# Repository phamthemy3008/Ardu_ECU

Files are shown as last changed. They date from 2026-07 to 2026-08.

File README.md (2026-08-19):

# Ardu_ECU — ECU Manual V1 (Version 7.9)

ECU (Engine Control Unit) cho động cơ phản lực mô hình mini (Enjet E86), chạy trên vi điều khiển ESP32.
Phiên bản **Manual V1** tập trung vào điều khiển thủ công và tự động qua **Web Serial API** & **Over-The-Air (OTA)**, đảm bảo độ tin cậy và chống nhiễu cao nhất trong môi trường công nghiệp/motor.

---

## Cấu Trúc Project

```
Ardu_ECU/
│
├── PROJECT_CURRENT/           ← Dự án đang phát triển (bắt đầu từ đây)
│   ├── Firmware/              
│   │   └── ECU_ManualV1/
│   │       └── ECU_ManualV1.ino   ← Code ESP32 (v7.9, mở bằng Arduino IDE / GitHub Actions)
│   ├── Tools/                 
│   │   └── index.html             ← Web Dashboard (v7.9, mở bằng Chrome/Edge)
│   ├── Hardware/                  ← Sơ đồ nguyên lý và Netlist PCB
│   └── Docs/                      ← Tài liệu kỹ thuật & Hướng dẫn triển khai
│
├── TEST/                      ← Firmware test riêng lẻ
├── REFERENCES/                ← Tài liệu và mã nguồn tham khảo
└── README.md
```

---

## Hướng Dẫn Chạy Web Dashboard Trên Windows 11 (Không Cần Cài Thêm Gì)

Web Dashboard được thiết kế theo chuẩn **Standalone Native HTML5 / JS Vanilla & Web Serial API**.

> [!IMPORTANT]
> **Yêu cầu**: Máy tính **Windows 11** + Trình duyệt **Google Chrome** hoặc **Microsoft Edge**.  
> **KHÔNG CẦN CÀI THÊM PHẦN MỀM GÌ**: Không cần cài Node.js, Python, hay web server. Chạy hoàn toàn offline (Zero Dependencies).

1. **Thao tác khởi chạy (Chế độ mặc định - Không cần cài Node.js)**:
   - Mở thư mục `PROJECT_CURRENT/Tools/` trong File Explorer.
   - Click đúp chuột vào file `index.html` (hoặc nhấp chuột phải chọn *Open with -> Google Chrome / Microsoft Edge*).
   - Trình duyệt sẽ mở trực tiếp file `file:///C:/.../index.html`.

2. **Kết nối Serial qua USB**:
   - Cắm cáp USB nối ESP32 với máy tính.
   - Bấm nút **"🔌 Kết Nối USB COM"** ở góc phải Web Dashboard.
   - Chọn đúng cổng COM của ESP32 (ví dụ: `COM3`, `COM4` - chip `CP210x` hoặc `CH340`) và bấm **Connect**.
   - Trạng thái sẽ báo `CỔNG COM ĐÃ MỞ (115200 baud, CRC-8)` và truyền/nhận dữ liệu lập tức.

3. **Khả năng sử dụng tính năng AI khi chạy Local**:
   - **Khi mở trực tiếp `index.html` (`file:///...`)**: Tất cả tính năng điều khiển Bơm/Đề/Van, Đồ thị Telemetry, Dừng khẩn cấp, Bảng Cài đặt Ngưỡng an toàn & Lưu `localStorage` đều **hoạt động 100% hoàn hảo không cần mạng**. Tuy nhiên, nút **"🧠 Phân Tích Dữ Liệu Log & Telemetry AI"** sẽ báo lỗi do không có server backend trung gian để gọi Gemini API.
   - **Để bật đầy đủ tính năng Chẩn Đoán AI khi chạy ở máy local**:
     1. Cài đặt **Node.js** (Lựa chọn thêm nếu muốn dùng AI).
     2. Tạo file `.env` tại thư mục gốc với nội dung `GEMINI_API_KEY=mã_api_key_của_bạn` (lấy miễn phí tại Google AI Studio).
     3. Mở Terminal / CMD tại thư mục dự án và chạy lệnh: `npm start` (hoặc `node server.js`).
     4. Mở trình duyệt truy cập `http://localhost:3000` -> Sử dụng đầy đủ tính năng phân tích & chẩn đoán sự cố tự động bằng Gemini AI!

---

## Bắt Đầu Với Firmware ESP32

1. **Upload Firmware**:
   - Mở file `PROJECT_CURRENT/Firmware/ECU_ManualV1/ECU_ManualV1.ino` bằng Arduino IDE.
   - Chọn Board **ESP32 Dev Module**, Baudrate 115200.
   - Thư viện cần: `Adafruit_MAX31855`, `SD` (xung PWM được điều khiển trực tiếp qua bộ tạo xung LEDC phần cứng của ESP32).

---

## Tính Năng Nổi Bật (Version 5.9)

- **Ghi Log Telemetry & Sự Kiện Lên Thẻ SD (`/ECUxxx.CSV`)**:
  - Tự động ghi nhật ký định kỳ 2Hz và hàng đợi sự kiện lỗi (`sdLogEvent`) ra file CSV trên thẻ MicroSD.
  - Các lệnh quản lý log qua Serial: `sdstatus`, `sdtest`, `set sdlog on|off`.

- **Tùy Chỉnh Ngưỡng An Toàn Trên Web UI (Safety Thresholds)**:
  - Cho phép thiết lập và lưu trên giao diện Web các ngưỡng: **PEGT 3s Max**, **EGT Max**, và **Max RPM**.
  - Dữ liệu được lưu vào **localStorage** của trình duyệt, tự động đồng bộ tới ECU khi kết nối và lưu vào `/ECUCFG.TXT` trên thẻ SD.

- **Cảnh Báo & Bảo Vệ An Toàn Tự Động**:
  - `ERR:E06` — Bảo vệ Quá Vòng Tua (Overrev) khi RPM vượt `Max RPM`.
  - `ERR:E02` — Bảo vệ Quá Nhiệt (Overheat) khi PEGT 3s hoặc EGT trực tiếp vượt ngưỡng cài đặt.
  - Khóa liên động 2 chiều Bơm - Van (`ERR:E01`, `EV:A01`, `EV:A02`).
  - Dừng khẩn cấp thổi khí làm mát buồng đốt (`estop` / `EV:A03`).
  - Nút cứng vật lý đa năng `BTN1` (IO22): Nhấp < 3s -> Dừng Khẩn Cấp làm mát; Giữ >= 3s -> Dừng Toàn Bộ (Full Shutdown).

- **Thuật Toán Gia Tốc Mượt Bơm & Đề (Smooth Ramps)**:
  - Pump Smoothstep S-Curve Ramp (1.5s): Đẩy ga nhiên liệu mượt chống dập lửa.
  - Starter Exponential Ramp (1.0s): Tăng ga đề theo đường cong mũ thắng ma sát nghỉ.
  - Công tắc Bật/Tắt ramp độc lập trên Web UI (`set pumpramp on|off`, `set starterramp on|off`).

- **Bộ Lọc RPM 7 Tầng Chuyên Sâu & Giao Thức Bảo Mật CRC-8**:
  - Loại bỏ hoàn toàn nhiễu cao tần từ ESC/Motor và đảm bảo tính toàn vẹn tín hiệu UART.

---

## Sơ Đồ Chân (Pinout) ESP32

| Thiết bị | Chân GPIO | Chú thích |
|---|---|---|
| **Cảm biến nhiệt (MAX31855)** | CLK=18, CS=5, DO=19 | Giao tiếp SPI (VSPI) |
| **Cảm biến vòng tua (RPM)** | 33 | Cảm biến từ/quang (KMZ10A / Hall) |
| **Bơm nhiên liệu (Pump)** | 26 | Tín hiệu PWM điều khiển ESC (LEDC CH0) |
| **Mô-tơ Đề (Starter)** | 25 | Tín hiệu PWM điều khiển ESC (LEDC CH1) |
| **Van nhiên liệu 1 (Valve 1)** | 17 | Tín hiệu Digital (Relay/Mosfet) |
| **Van khởi động 2 (Valve 2)** | 16 | Tín hiệu Digital (Relay/Mosfet) |
| **Đánh lửa (Igniter)** | 32 | Tín hiệu Digital (Relay/Mosfet) |
| **Thẻ nhớ MicroSD** | CS=13, SCK=14, MOSI=23, MISO=27 | Giao tiếp SPI (HSPI) |
| **Nút nhấn vật lý (BTN1)** | 22 | Nút đa năng Dừng Khẩn Cấp / Shutdown |
| **Đèn LED Trạng Thái** | 2 | Nháy Heartbeat 1Hz |

---

## Khắc Phục Sự Cố (Troubleshooting)

1. **Lỗi không kết nối được Web Serial:**
   - Trình duyệt báo `The port is already open`: Đảm bảo bạn đã đóng Serial Monitor trong Arduino IDE. Sử dụng nút "❌ Ngắt Kết Nối" trên Web để nhả cổng COM trước khi upload code.
   - Trình duyệt không có nút kết nối: Hãy dùng Chrome hoặc Edge bản mới nhất.

2. **Log báo `[RX NOISE DROPPED]` liên tục:**
   - Bình thường khi mạch chịu nhiễu điện từ nặng từ ESC/Motor. Firmware đã chặn các lệnh lỗi nhờ CRC-8.
   - Khắc phục phần cứng: Tiếp đất (GND) chung, xoắn cặp dây UART, sử dụng lõi Ferrite chống nhiễu.

3. **Thông báo lỗi EGT `ERR(SHORT_VCC)` hoặc `ERR(OPEN)`:**
   - Kiểm tra lại dây Thermocouple K (MAX31855). Dây bị đứt, lỏng, hoặc chạm vỏ máy.

4. **Lệnh debug RPM mới qua Serial:**
   - `rpmlearn`: Xem bảng 20 bin PWM ↔ RPM đã tự động học được.
   - `rpmlearn reset`: Xóa dữ liệu học và bắt đầu học lại.

---

## Liên Hệ & Đóng Góp

- Mọi đóng góp đều được chào đón. Xem thêm tại [GitHub Issues](https://github.com/phamthemy3089/Ardu_ECU/issues).

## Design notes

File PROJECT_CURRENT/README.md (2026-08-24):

# PROJECT_CURRENT — ECU Manual V1 (Version 8.0)

**Trạng thái**: Phiên bản v8.0 (Hoàn thiện & Ổn định)  
**Cập nhật**: 2026-08-24  

---

## Cấu Trúc Thư Mục

```
PROJECT_CURRENT/
│
├── Firmware/ECU_ManualV1/
│   └── ECU_ManualV1.ino           ← Firmware ESP32 (Arduino IDE / GitHub Actions, v8.0)
│
├── Tools/
│   └── index.html                 ← Web Dashboard & Web Serial ESP32 Flasher (Chrome/Edge, v8.0)
│
├── Hardware/
│   ├── 3D Printable Files/        ← File in 3D (Bendix Sleeve, Giá đỡ Motor Đề)
│   │   ├── Bendix Sleeve_10mm_NoSpring_Reinforced.stl   ← Ống áo Bendix cốt 10mm (Tự văng không lò xo)
│   │   ├── Bendix Sleeve_10.4mm_NoSpring_Reinforced.stl ← Ống áo Bendix cốt 10.4mm (Tự văng không lò xo)
│   │   ├── Bendix Sleeve_Reinforced.stl                ← Ống áo Bendix cốt 9mm (Bản gia cường)
│   │   ├── Bendix Sleeve.stl                           ← Ống áo Bendix cốt 9mm (Bản gốc)
│   │   ├── Brushless motor mount.stl                   ← Giá đỡ motor không chổi than
│   │   └── Brushed motor mount.stl                     ← Giá đỡ motor chổi than
│   ├── ECU_JET_20260723.net       ← Netlist PCB (PADS)
│   └── SCH_MinijetengineECU_20260723.json ← Sơ đồ mạch ECU (EasyEDA JSON)
│
├── Docs/
│   ├── JETENGINE_ECU_DESIGN_REFERENCE.md  ← Tài liệu thiết kế ECU
│   ├── STARTER_MOTOR_IMPLEMENTATION_GUIDE.md  ← Hướng dẫn triển khai Starter
│   ├── CHANGELOG.md               ← Nhãn lịch sử các phiên bản
│   └── BringUp_Logs/              ← Dữ liệu đo RPM thực tế (DSO152, Serial)
│
└── README.md                      ← File hướng dẫn này
```

---

## Hướng Dẫn Chạy Web Dashboard Trên Windows 11 (Không Cần Cài Thêm Gì)

Ứng dụng Web Dashboard được thiết kế theo tiêu chuẩn **Standalone Native HTML5 & Web Serial API**.

> [!IMPORTANT]
> **Yêu cầu hệ thống**: Máy tính chạy **Windows 11** + Trình duyệt **Google Chrome** hoặc **Microsoft Edge** (đã tích hợp sẵn Web Serial API từ phiên bản 89 trở lên).  
> **TUYỆT ĐỐI KHÔNG CẦN CÀI THÊM GÌ**: Không cần Node.js, không cần Python, không cần cài server web, không cần cài thêm thư viện phụ trợ (Zero Dependencies / Offline Ready).

### Các bước khởi chạy Web Dashboard:

1. **Khởi chạy giao diện (Chế độ mặc định - Offline 100% không cần Node.js)**:
   - Mở thư mục `PROJECT_CURRENT/Tools/` trên máy tính.
   - **Click đúp chuột** vào file `index.html` (hoặc chuột phải chọn *Open with -> Google Chrome / Microsoft Edge*).
   - Trình duyệt sẽ mở trực tiếp file dạng `file:///C:/.../PROJECT_CURRENT/Tools/index.html`.

2. **Kết nối USB COM với ESP32**:
   - Cắm cáp USB (MicroUSB / Type-C) nối board ESP32 vào máy tính Windows 11.
   - Trên giao diện Web Dashboard, bấm nút **"🔌 Kết Nối USB COM"** ở góc trên bên phải.
   - Trong cửa sổ popup của trình duyệt, chọn đúng cổng COM tương ứng của ESP32 (ví dụ: `COM3`, `COM4` - thường ghi tên chip USB `CP210x` hoặc `CH340`).
   - Bấm **Connect**. Màn hình console sẽ báo `CỔNG COM ĐÃ MỞ (115200 baud, CRC-8)` và toàn bộ dữ liệu telemetry sẽ cập nhật thời gian thực.

3. **Tính Năng Nạp Firmware Trực Tiếp Trên Browser (Web Serial ESP32 Flasher)**:
   - Web Dashboard tích hợp thư viện `esptool-js` giúp người dùng nạp file `firmware.bin` trực tiếp vào ESP32 thông qua trình duyệt mà không cần cài đặt Python hay Arduino IDE.
   - Bấm nút **"🔥 Nạp Firmware USB"**, chọn file `firmware.bin`, đưa ESP32 về chế độ Flash (nếu cần) và bấm **Program Firmware**.

4. **Khả năng sử dụng tính năng Chẩn Đoán AI khi chạy ở máy Local**:
   - **Chạy trực tiếp HTML (`file:///...`)**: Tất cả các tính năng cốt lõi (điều khiển Bơm/Đề/Van, Đồ thị Telemetry, Dừng khẩn cấp, Bảng Cài đặt Ngưỡng an toàn & Lưu `localStorage`, Cấu hình Wi-Fi/OTA) **hoạt động 100% mượt mà không cần mạng**. Riêng nút **"🧠 Phân Tích Dữ Liệu Log & Telemetry AI"** cần backend server để gọi API Gemini.
   - **Để bật tính năng Chẩn Đoán AI Gemini trên máy Local**:
     1. Cài đặt **Node.js** trên Windows 11 (nếu chưa có).
     2. Tạo file `.env` tại thư mục gốc project với nội dung: `GEMINI_API_KEY=mã_key_của_bạn` (lấy tại Google AI Studio).
     3. Chạy lệnh `npm start` (hoặc `node server.js`) trong Terminal.
     4. Mở trình duyệt tại địa chỉ `http://localhost:3000` -> Sử dụng đầy đủ tính năng phân tích & chẩn đoán lỗi chuyên sâu bằng Gemini AI!

5. **Lưu ý trên Windows 11 & Khắc phục sự cố**:
   - **Driver USB**: Windows 11 đa số tự động nhận diện chip CH340 / CP2102. Nếu không thấy xuất hiện cổng COM trong danh sách, hãy cài driver `CP210x Universal Windows Driver` hoặc `CH340 Windows Driver`.
   - **Lỗi Cổng COM bị chiếm dụng (`The port is already open`)**: Hãy chắc chắn rằng bạn đã tắt **Serial Monitor** hoặc **Serial Plotter** trong phần mềm Arduino IDE (hoặc các phần mềm terminal như PuTTY) trước khi bấm kết nối trên Web.

---

## Hướng Dẫn Upload Firmware ESP32

### Cách 1: Tự động Biên Dịch & Nạp Qua CI/CD GitHub Actions (Khuyên dùng)
- Mỗi khi push code lên nhánh `main`, GitHub Actions (`.github/workflows/compile-firmware.yml`) sẽ tự động cài đặt `arduino-cli`, biên dịch mã nguồn `ECU_ManualV1.ino` và tạo sẵn file `firmware.bin` tại thư mục `PROJECT_CURRENT/Firmware/ECU_ManualV1/firmware.bin`.
- Bạn chỉ cần tải file `firmware.bin` về và dùng nút **"🔥 Nạp Firmware USB"** trên Web Dashboard để nạp.

### Cách 2: Upload Bằng Arduino IDE Thủ Công
1. Mở file `Firmware/ECU_ManualV1/ECU_ManualV1.ino` bằng **Arduino IDE**.
2. Chọn Board: **ESP32 Dev Module** (hoặc NodeMCU-32S).
3. Thư viện phần cứng cần có trong Arduino IDE:
   - `Adafruit_MAX31855` (đọc cảm biến nhiệt độ EGT qua SPI).
   - `SD` (đọc/ghi cấu hình & log dữ liệu ra thẻ MicroSD).
   - *Lưu ý*: Tín hiệu ESC PWM cho Bơm & Đề được điều khiển bằng bộ tạo xung LEDC phần cứng có sẵn của ESP32 — **không** cần thư viện `ESP32Servo`.
4. Upload Firmware → Baudrate Serial mặc định **115200 baud**.

---

## Tính Năng Chính & Cải Tiến (v8.0)

- **Kiến Trúc Đa Nhân FreeRTOS Cô Lập Tuyệt Đối (Multi-Core Isolation)**:
  - **Core 1 (Engine Control Core)**: Xử lý độc quyền các tác vụ thời gian thực mức phần cứng (RPM ISR, cảm biến EGT SPI, điều xung ESC PWM, bộ lọc RPM 7 tầng, logic ngắt khẩn cấp). Đảm bảo tính thời gian thực 100% không bị trễ do mạng hay thẻ SD.
  - **Core 0 (System & Network Core)**: Đảm nhận việc ghi thẻ SD bất đồng bộ (`sdQueue`), kết nối Wi-Fi, xử lý giao thức Web Serial, quét mạng Wi-Fi không chặn (`WiFi.scanNetworks(true)`) và cập nhật firmware qua mạng Async OTA (`ArduinoOTA`).

- **Cập Nhật Firmware Qua Mạng OTA Bất Đồng Bộ (`ArduinoOTA`)**:
  - Hỗ trợ nạp firmware không dây qua mạng Wi-Fi local mà không cần cắm cáp USB.
  - Tự động ngắt toàn bộ động cơ (`allOff()`) khi bắt đầu nhận bản nạp OTA để đảm bảo an toàn tuyệt đối.

- **Trình Quét Mạng Wi-Fi Không Chặn & Modal Chọn Mạng**:
  - Lệnh `wifi scan` hoạt động ở chế độ Async không gây đơ lag thuật toán tính toán RPM/EGT.
  - Web Dashboard hiển thị danh sách các mạng Wi-Fi quét được, nhấp chuột để chọn SSID tự động và điền mật khẩu.

- **Ghi Log Telemetry & Sự Kiện Lên Thẻ SD (`/ECUxxx.CSV`) Kháng Lỗi C++**:
  - Tự động tạo file nhật ký xoay vòng (`ECU000.CSV` .. `ECU999.CSV`) khi khởi động.
  - Hàng đợi log sự kiện phi đối xứng `sdLogEvent` hỗ trợ hai kiểu tham số `sdLogEvent(const char*)` và `sdLogEvent(const String&)` có bảo vệ null-pointer, đẩy vào queue FreeRTOS truyền dữ liệu thread-safe.

- **Tùy Chỉnh Ngưỡng An Toàn Linh Hoạt (Safety Thresholds Configuration)**:
  - Cho phép người dùng trực tiếp thay đổi và lưu các ngưỡng an toàn trên giao diện Web Dashboard:
    - **PEGT 3s Max (°C)**: Giới hạn dự báo nhiệt độ 3s (mặc định 740°C, tùy chỉnh 300 - 1200°C).
    - **EGT Max (°C)**: Giới hạn nhiệt độ EGT đo trực tiếp (mặc định 800°C, tùy chỉnh 300 - 1200°C).
    - **Max RPM**: Giới hạn vòng tua tối đa chống overrev (mặc định 160.000 RPM, tùy chỉnh 5.000 - 250.000 RPM).
  - Tự động lưu vào **localStorage** của trình duyệt và truyền ngay các lệnh thiết lập (`set pegtmax`, `set egtmax`, `set maxrpm`) tới ECU khi kết nối thành công. Đồng thời được lưu lâu dài vào file cấu hình `/ECUCFG.TXT` trên thẻ SD.

- **Bảo Vệ Chống Overrev & Bùng Nhiệt Toàn Diện**:
  - `ERR:E06`: Tự động ngắt Bơm nhiên liệu và kích hoạt Dừng Khẩn Cấp khi vòng tua lọc `fRpm` vượt ngưỡng `maxRpmLimit`.
  - `ERR:E02`: Tự động ngắt Bơm nhiên liệu và kích hoạt làm mát khi `PEGT 3s > pegtLimit` hoặc `EGT > egtMaxLimit`.

- **Thuật Toán Gia Tốc Mượt Bơm (Pump S-Curve Smoothstep Ramp 1.5s)**: Gia tốc ga nhiên liệu mượt mà theo đa thức bậc 3 ($3x^2 - 2x^3$), giúp động cơ rú ga mượt hệt như máy bay thật, chống sặc dầu & dập lửa.

- **Thuật Toán Gia Tốc Đề (Starter Exponential Ramp Up 1.0s)**: Gia tốc lực kéo mô-tơ Đề theo đường cong mũ lũy thừa, thắng lực ma sát nghỉ ban đầu mà không làm xóc nhông Bendix hay kẹt motor.

- **Bộ Lọc RPM 7 Tầng Chuyên Sâu**: Min Pulse → Dynamic Mask 75% → Median-5 → Dynamic Outlier Guard → Rate Limiter → Adaptive PWM-Aware Learning (Monotonicity Floor + Hysteresis) → Cascaded Dual-EMA Bậc 2.

- **Dừng Khẩn Cấp Thổi Khí Nóng (`estop`)**: Ngắt Bơm/Lửa/Van nhưng tự động bật/giữ Mô-tơ Đề 1300 µs để làm mát buồng đốt khi EGT > 80°C.

- **Nút Cứng Vật Lý Đa Năng (`BTN1` / IO22)**:
  - Nhấp 1 lần (< 3s): Kích hoạt Dừng Khẩn Cấp làm mát.
  - Nhấn giữ 3s (>= 3s): Dừng Toàn Bộ (Full Shutdown, ngắt cả Đề).

- **Khóa An Toàn 2 Chiều (Pump-Valve Interlock)**:
  - Không cho bật Bơm khi cả 2 van nhiên liệu đang ĐÓNG (`ERR:E01`).
  - Tự động ngắt Bơm khi cả 2 van bị đóng (`EV:A02`).
  - Tự động đóng cả 2 van khi tắt Bơm (`EV:A01`).

- **Giao Thức Bảo Mật CRC-8 & Web Serial API**: Loại bỏ 100% lệnh rác do nhiễu cao tần từ ESC/Motor.

---

## Bảng Mã Sự Kiện & Mã Lỗi (Event & Error Code Dictionary)

| Mã Serial | Loại | Ý Nghĩa | Thông Báo Tiếng Việt Hiển Thị Trên Web Dashboard |
|---|---|---|---|
| `ERR:E01` | Cảnh báo | Bật Bơm khi cả 2 van đóng | `⚠️ CẢNH BÁO AN TOÀN: Cả 2 van nhiên liệu đều đang ĐÓNG! Vui lòng mở ít nhất 1 van trước.` |
| `ERR:E02` | Khẩn cấp | Quá nhiệt PEGT / EGT vượt ngưỡng | `🛑 CẢNH BẢO QUÁ NHIỆT: Nhiệt độ EGT/PEGT vượt ngưỡng an toàn! Đã tự động NGẮT BƠM & THỔI LÀM MÁT.` |
| `ERR:E06` | Khẩn cấp | Quá vòng tua RPM > Max RPM | `🛑 CẢNH BẢO QUÁ VÒNG TUA: Vòng tua (RPM) vượt ngưỡng tối đa! Đã tự động NGẮT BƠM NHIÊN LIỆU.` |
| `EV:A01`  | Thông tin | Tắt Bơm -> Tự đóng 2 van | `ℹ️ TỰ ĐỘNG KHÓA: Đã Tắt Bơm -> Tự động đóng cả 2 Van nhiên liệu (V1 & V2).` |
| `EV:A02`  | Thông tin | Đóng 2 van -> Tự ngắt Bơm | `ℹ️ TỰ ĐỘNG KHÓA: Đã đóng cả 2 Van -> Tự động ngắt Bơm nhiên liệu.` |
| `EV:A03`  | Khẩn cấp | Dừng Khẩn Cấp -> Thổi khí 1300µs | `🛑 DỪNG KHẨN CẤP: Ngắt Bơm & Lửa/Van -> Tự động bật Đề 1300µs thổi khí làm mát.` |
| `EV:A04`  | Thông tin | Dừng Khẩn Cấp -> Máy nguội <= 80°C | `ℹ️ DỪNG KHẨN CẤP: Đã ngắt Bơm & Lửa/Van (Máy đã nguội <= 80°C).` |
| `EV:A05`  | Khẩn cấp | Nút 3s / Dừng Toàn Bộ | `⚡ DỪNG TOÀN BỘ: Đã ngắt 100% tất cả thiết bị (Bơm, Đề, Lửa, Van).` |

---

## Pinout ESP32

| Chức năng | GPIO | Ghép nối / Chú thích |
|---|---|---|
| MAX31855 CLK/CS/DO | 18 / 5 / 19 | SPI (VSPI) |
| RPM Sensor | **33** | Cảm biến từ/quang (KMZ10A / Hall) |
| Pump ESC | 26 (LEDC CH0) | Tín hiệu PWM ESC Bơm nhiên liệu |
| Starter ESC | 25 (LEDC CH1) | Tín hiệu PWM ESC Mô-tơ Đề |
| Valve 1 / Valve 2 | 17 / 16 | Tín hiệu Digital điều khiển van |
| Ignition/Glow | 32 | Tín hiệu Digital điều khiển đánh lửa |
| SD CS/SCK/MOSI/MISO | 13 / 14 / 23 / 27 | Thẻ nhớ MicroSD (HSPI) |
| User Button (BTN1) | 22 | Nút nhấn cứng đa năng (Active LOW) |
| Status LED | 2 | Nháy Heartbeat 1Hz |

---

## Cảnh Báo An Toàn

- ESP32 chỉ chịu **3.3V** — dùng level converter cho tín hiệu 5V
- Chỉ dùng **thermocouple loại K**
- Cảm biến RPM KMZ10A cần hiệu chỉnh trimpot **RP1/RP2/RP3** trước khi dùng
- ESP32 cần nguồn điện riêng (không cấp qua USB khi motor chạy)

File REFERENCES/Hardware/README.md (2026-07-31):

# Hardware Directory

Thư mục chứa tất cả các tệp liên quan đến phần cứng của dự án Ardu_ECU.

## 📂 Sub-directories

### **Schematics/** - Sơ đồ mạch điện
Chứa tất cả các tệp sơ đồ và thiết kế mạch điện.

**Files**:
- `ECU Rev9-10 Schematic.pdf` - Schema cho Rev 9 và 10
- `Schematic_Ardu ECU_Rev 11.pdf` - Schema cho Rev 11 (ổn định hiện tại)
*(Lưu ý: Các file schema mới nhất nằm trong thư mục `../../PROJECT_CURRENT/Hardware/`)*

### **Components/** - Linh kiện và tài liệu
Chứa hình ảnh và thông số kỹ thuật của các linh kiện được sử dụng.

**Components**:
- `5v-to-3-3v-logic-level-converter-500x500.jpg` - Logic level converter
- `CK1602 Power Supply.jpg` - Power supply unit
- `ESP32 Dev Kit.jpeg` - Main microcontroller (NodeMCU 32S)
- `LR-7843.jpg` - Additional component

### **3D Printable Files/** - Các file in 3D
Chứa các file STL cho các bộ phận cơ học có thể in 3D.

**Files**:
- `Bendix Sleeve.stl` - Sleeves for starter motor
- `Brushed motor mount.stl` - Mount cho động cơ brushed
- `Brushless motor mount.stl` - Mount cho động cơ brushless

## 🔧 Hardware Overview

### **Core Components**:
1. **Microcontroller**: ESP32 DevKit V1 (NodeMCU-32S)
2. **Thermocouple Reader**: MAX31855 (for EGT measurement)
3. **SD Card Module**: For data logging
4. **Power Supply**: CK1602 unit
5. **Logic Level Converter**: 5V to 3.3V conversion
6. **Control Outputs**:
   - Starter motor controller (brushed or brushless)
   - Fuel pump controller (ESC or similar)
   - Ignition control (glow plug driver)
   - Gas valve solenoid control (MOSFET module)

### **Sensors**:
- **EGT Sensor**: K-type Thermocouple with MAX31855
- **RPM Sensor**: Magnetic (Hall effect) or Optical sensor
- **Optional**: Pressure sensors, Load cells

## 📐 Design Files

### **Latest Reference Files** (2026-07-23):
- `../../PROJECT_CURRENT/Hardware/ECU_JET_20260723.net` - Netlist mạch ECU mới nhất (gồm cả RPM sensor)
- `../../PROJECT_CURRENT/Hardware/SCH_MinijetengineECU_20260723.json` - Current ECU design schema

These are reference files from the current system implementation (ManualV1 v5.3) and can be used as guidelines for future designs.

## 🚀 Assembly Notes

1. **PCB Layout**: Refer to schematics for component placement
2. **3D Printed Parts**: Use `.stl` files for 3D printing
3. **Component Mounting**: Follow schematic for orientation and pin connections
4. **Wiring**: Carefully follow schematic connections to avoid damage

## ⚠️ Important Warnings

- **Voltage**: ESP32 operates at 3.3V - use logic level converter for 5V devices
- **Power**: Use proper power supply rated for your application
- **Thermocouple**: K-type only - do not use other types
- **High Temperature**: Mount components away from engine exhaust

## 📊 Revision History

| Revision | Date | Key Features |
|---|---|---|
| Rev 9 | Early | Initial design |
| Rev 10 | - | WiFi control, OLED display |
| Rev 11 | - | SD Card, dual-core processing, major redesign |
| Rev 12 TC10 | Legacy | Multi-sensor support, Kero start |
| TestV1_EGT_DRY_START | Legacy | Firmware cũ, có Auto-start, WiFi |
| ManualV1 (v5.3) | Current | Bản hiện tại, Manual Serial Control, Compact Event Codes, Interlock & Toast Banners |

---

For detailed firmware information, see [Firmware/README.md](../Firmware/README.md)

For project overview, see [README.md](../README.md)

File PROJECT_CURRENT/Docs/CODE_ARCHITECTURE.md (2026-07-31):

# ECU Manual V1 Firmware — Code Architecture & Understanding Guide

**Firmware**: `ECU_ManualV1.ino` (Version 4.2)
**Tools**: `index.html` (Web Serial Dashboard)
**Platform**: ESP32 (NodeMCU-32S), Arduino core 2.x **or** 3.x
**Language**: Arduino C++

> **Note on line numbers**: this guide navigates by **function / symbol name**, not
> line numbers — the firmware evolves and hard line references drift. Use your
> editor's symbol search. A companion changelog of behaviour changes lives in
> `CODE_REVIEW_FINDINGS.md`.

---

## 🏗️ Overall Architecture

State-machine firmware. One non-blocking `loop()` drives everything:

```
loop():
  1. server.handleClient()          (Web UI, if started)
  2. drain Serial -> handleCommand()
  3. handleUserButton()
  4. manual auto-off timers          (ign / starter / pump / valve1 / valve2)
  5. updateActiveTest()              (Test Wizard countdowns)
  6. isStage2Armed()                 (auto-disarm after 10s)
  7. updateRpm(); updateEgt()        (sensors)
  8. mode switch:  updateStarting / updateIdling / updateOperating / updateCooldown
  9. checkFailures()                 (all aborts evaluated here)
  10. applyOutputs()                 (write ESC PWM + digital outputs)
  11. updateStatusLed()
  12. updateSdTelemetry(); flushSdEventQueue()   (deferred SD writes)
  13. printStatus(false)             (throttled serial status)
```

Fuel/RPM/EGT control is re-evaluated every loop; safety checks (`checkFailures`)
run **after** the mode update and **before** `applyOutputs()`.

---

## ⚙️ PWM Driver — raw LEDC (not ESP32Servo)

ESC outputs (pump + starter) are driven by the ESP32 **LEDC** peripheral directly,
**not** the `ESP32Servo` library (which produced an unstable pulse on some core
versions and stuttered the ESC — see `CLAUDE.md`).

```cpp
escAttach(pin, legacyChannel)   // ledcAttach() on core >=3, ledcSetup+ledcAttachPin on core <3
escWriteUs(pin, legacyChannel, us)  // duty = us * 65535 / 20000  (50 Hz, 16-bit)
```
- 50 Hz frame, 16-bit resolution → 1000 µs = duty 3276, 2000 µs = duty 6553.
- Core version detected via `ESP_ARDUINO_VERSION_MAJOR`.

> **Arduino gotcha**: because `escAttach`/`escWriteUs` are the first functions in the
> sketch, the IDE injects auto-generated prototypes ahead of the enum definitions.
> The state enums (`EcuMode`, `StartStage`, `RpmNoiseLevel`, `TestId`, `TestResult`)
> are therefore **forward-declared** near the top so those prototypes compile.

---

## 🎯 Core State Machine

### ECU Modes
```cpp
enum EcuMode : uint8_t {
  MODE_WAITING, MODE_STARTING, MODE_IDLING,
  MODE_OPERATING, MODE_COOLDOWN, MODE_ABORTED
};
```

### Start Stages
```cpp
enum StartStage : uint8_t {
  ST_NONE, ST_PURGE, ST_SPINUP_PREHEAT,
  ST_INTRO_FUEL, ST_POST_IGNITION_HEAT, ST_ACCEL_TO_IDLE
};
```

### Mode transitions
```
WAITING
  │ arm (button hold 2s / arm2) then start (button hold 3s / startidle)
  ▼
STARTING  (ST_PURGE → ST_SPINUP_PREHEAT → ST_INTRO_FUEL → ST_POST_IGNITION_HEAT → ST_ACCEL_TO_IDLE)
  │ idle RPM reached  (enterMode records runningSinceMs here)
  ▼
IDLING ⇄ OPERATING   (throttle >0 / =0 toggles; does NOT reset runningSinceMs)
  │ soft stop / any abort
  ▼
COOLDOWN (starter airflow, fuel/ign/valves OFF)
  │ min time + (EGT cool OR timeout)
  ▼
WAITING            (after soft stop)   or   ABORTED (after an abort)
```

`ABORTED` is left only by `clearabort` (sets `abortAcknowledged`) or the physical
button hold. `stop`/`off` do **not** clear ABORTED (interlock).

---

## 📊 Key Data Structures

### Config (`struct Config cfg`)
Runtime configuration; the struct values are **power-on defaults**, most are
overridable at runtime via `set ...` (Serial/Web). Notable fields:

| Field | Default | Meaning |
|---|---|---|
| `autoStartEnabled` | false | Auto-idle at boot (off) |
| `requireEgtForStart` / `allowDryStartWhenEgtFault` | true | EGT gating / dry-start fallback |
| `requireRpmForStart`, `abortOnEgtFault`, `abortOnRpmFault` | true | Abort enables |
| `ignitionThresholdC` | 100 | "combusting" / ignition threshold |
| `maxEgtC` | 680 | OVER_TEMP abort limit |
| `maxTempGradientCps` | 200 | EGT rise-rate limit (steady state only) — `set maxgrad` |
| `idleRpm` / `maxRpm` / `rpmTolerance` | 42000 / 110000 / 5000 | RPM targets & deadband |
| `flameoutRpm` / `starterReleaseRpm` | 15000 / 24000 | flame-out / starter release |
| `starterPurgeUs` / `starterSpinUs` / `starterAssistUs` | 1100 / 1200 / 1200 | crank PWM — `set purgeus/spinus/assistus` |
| `introFuelUs` | 1160 (~50 ml/min) | light-off fuel dose (kept **< idle**) — `set intro` |
| `idleFuelUs` / `maxFuelUs` | 1175 / 1260 | idle / max fuel — `set idleus/maxus` |
| `pumpTestUs` | 1210 | bench pump-prime PWM, **separate** from introFuelUs — `set pumptestus` |
| `commWatchdogEnabled` / `commTimeoutMs` | true / 8000 | operator-link watchdog |
| cooldown / accel-to-idle / ramp timings | — | various `set ...` |

> All PWM/limit tuning setters are **rejected unless WAITING/ABORTED** so a stray
> command can't move a live setpoint or the protection envelope mid-run.

### EgtState `egt`
`ok, c, prevC, gradientCps, fault, lastReadMs, lastGoodMs`.

### RpmData `rpmData`
`rpm` (chosen source), `rpmPeriod` (instantaneous), `rpmWindow` (100 ms average),
`avgIntervalUs`, `jitterPct` (CV = stddev/mean), `rejectPct`, `rpmDiffPct`,
`rawEdges/acceptedWindow/rejectedEdges`, `noise` (RpmNoiseLevel), `signalRecent`,
`restPulseNoise`.

---

## 🔌 Pin Configuration

| Pin | Function | Dir | Type |
|-----|---|-----|---|
| 18 / 5 / 19 | EGT CLK / CS / DO | — | SPI (MAX31855) |
| 33 | RPM sensor | IN | Digital (ISR) |
| 26 | Pump ESC | OUT | LEDC PWM 50 Hz |
| 25 | Starter ESC | OUT | LEDC PWM 50 Hz |
| 17 | Valve 1 (Start solenoid) | OUT | Digital |
| 16 | Valve 2 (Main oil) | OUT | Digital |
| 32 | Ignition / glow | OUT | Digital |
| 22 | User button | IN | Digital (active-low) |
| 2 | Status LED | OUT | Digital (active-low) |
| 13 / 14 / 23 / 27 | SD CS / SCK / MOSI / MISO | — | SPI |

Valve roles (per EnJet E86/G3 manual): **Valve1** = start solenoid, open only
during `MODE_STARTING`; **Valve2** = main oil valve, open whenever fuel is commanded.

---

## 🔋 Subsystems

### 1. EGT (MAX31855)
- `updateEgt()` polls every `EGT_READ_PERIOD_MS` (120 ms); `readError()` then
  `readCelsius()`; `isnan`/fault → `egt.ok=false`, gradient zeroed.
- `gradientCps` = ΔT/Δt.
- **Two look-aheads with different jobs**:
  - Fuel control: 3 s projected temp (`egt.c + 3·gradient ≥ maxEgtC`) — steady state.
  - OVER_TEMP abort: short `EGT_ABORT_LOOKAHEAD_S = 0.2 s` — compensates ~1 sample of
    read staleness so a fast rise can't overshoot `maxEgtC` by a sample.
- **Stuck-sensor hint** (log only, never aborts): if `egt.c` is byte-for-byte
  unchanged for `EGT_STUCK_WARN_MS` (6 s) while combusting, logs a warning — a
  frozen-but-valid thermocouple isn't caught by open/short fault detection.
- **Dry-start**: if EGT is OPEN, `startidle` becomes a starter/RPM-only test
  (pump/valves/ign forced OFF every loop); real fuel start still needs valid EGT.

### 2. RPM sensing (ISR on GPIO 33)
- `rpmISR()` timestamps each edge with `micros()` (coerced to non-zero to avoid the
  "no edge yet" sentinel colliding at the ~71 min wrap).
- **Two-stage de-glitch**: (a) fixed min quiet-period `rpmMinPulseUs` (120 µs default,
  `set rpmfilter`); (b) adaptive half-period mask — reject an edge closer than half
  the last accepted period (an isolated EMI spike after a quiet gap).
- `updateRpm()` snapshots ISR counters inside `noInterrupts()` (the only `uint64_t`
  accumulators are read atomically there), computes:
  - `rpmWindow = accepted · 60e6 / (windowUs · ppr)`  (100 ms average)
  - `rpmPeriod = 60e6 / (lastPeriod · ppr)`  (instantaneous, preferred when recent)
  - `jitterPct` = **coefficient of variation** (stddev/mean), so one stray interval
    doesn't swamp an otherwise-clean signal.
- **REST guard**: while WAITING with all outputs safe, isolated edges are treated as
  noise (`RPM_REST_NOISE`, control RPM forced 0) to stop 1–3 false pulses reading as RPM.

Noise classes (`classifyRpmNoise`):
```
NO_SIGNAL : no recent signal and raw==0
NOISY     : raw>1 & accepted==0 (a lone post-reset priming edge is NOT noise), OR rejected>=3/rejectPct>20, OR jitter>30% (>=5 intervals), OR rpmDiff>30%
WARN      : rejected>0/rejectPct>5,  OR jitter>15% (>=3 intervals),           OR rpmDiff>15%
CLEAN     : otherwise
REST_NOISE: rest-guard active
```

### 3. Fuel control (hybrid, closed-loop to RPM)
```
target RPM ──► fuelTargetUs (nudged ±fuelStepUs vs RPM error, gated by EGT)
                    │
             pumpUs ── ramps toward target 1 µs / step (accel/decel delays)
```
- Pump map (`kPumpMap`, µs → ml/min), interpolated by `flowFromUs`/`usFromFlow`:
  `1000→0, 1160→50, 1175→80, 1250→265, 1260→280, 1265→360, 1270→560, 1300→600`.
- **Over-temp emergency cut**: when `egtRequestsFuelCut()` fires, `pumpUs` steps down
  by `fuelCutStepUs` at the fast decel rate (~40 µs/s), not the old ~2 µs/s ramp that
  could never keep up before the hard abort.
- **Governed ceiling**: `updateOperating()` targets `maxRpm − rpmTolerance` at 100%
  throttle, so full throttle doesn't drive the engine into its own OVERSPEED abort.
- During `MODE_STARTING` the gradient / 3 s look-ahead fuel limiting is **skipped**
  (a fast EGT rise at light-off is expected); only absolute `maxEgtC` + the abort
  look-ahead protect there, so the start can actually reach idle.

### 4. User button (GPIO 22, active-low, 35 ms debounce)
```
WAITING : short=status · hold 2s=ARM
ARMED   : hold 3s=START IDLE           (button runs set runStartedByButton)
STARTING/IDLING/OPERATING : any press=SOFT STOP
ABORTED : hold 2s=clear (if EGT safe/deliberate)
```

### 5. Output control
`applyOutputs()` constrains ESC values to 1000–2000 µs and writes PWM + digital
outputs. `forceSafeOutputs()` slams everything safe (ESC 1000 µs, ign/valves OFF,
clears the valve auto-off timers; the ign/starter/pump timers are cleared in
`stage2Off()`/`beginAutoIdle()`). Manual bench outputs (ignpulse/starttest/
pumptest/valve-on) all have loop auto-off timers.

---

## 🚀 Start Sequence

```
ST_PURGE (purgeTimeMs 3s)         starter=starterPurgeUs(1100), no fuel/ign
ST_SPINUP_PREHEAT (preheatMs)     starter=starterSpinUs(1200), igniter ON (preheat); needs cranking RPM (starterProveMinRpm)
ST_INTRO_FUEL                     igniter still ON, valves open, fuel=introFuelUs(1160); wait ignition/fuel-confirm
ST_POST_IGNITION_HEAT             hold fuel, watch RPM rise; starter -> starterAssistUs(1200)
ST_ACCEL_TO_IDLE                  closed-loop fuel to idleRpm; starter releases; timeout=accelToIdleTimeoutMs(20s)
  └─ idle stable ► MODE_IDLING
```
Every stage is time-bounded (no infinite hang). Dry-start runs the same stages with
fuel/valves/ign forced OFF and its own RPM-test timeouts.

---

## 🔒 Safety — `checkFailures()` (runs every loop, not in WAITING/COOLDOWN/ABORTED)

Order and conditions:
1. **COMM_TIMEOUT** — only while RUNNING (IDLING/OPERATING) with no operator link
   within `commTimeoutMs`. **Exempt** for button-started runs (`runStartedByButton`);
   re-engages on any remote command. MODE_STARTING is deliberately NOT covered (the
   automated start outlasts `commTimeoutMs` with nothing to refresh the link, so
   covering it would false-abort a Serial-only start); the start is bounded instead
   by the per-stage timeouts.
2. **EGT_FAULT** — sensor invalid (unless dry-start).
3. **OVER_TEMP** — `egt.c ≥ maxEgtC` OR the 0.2 s look-ahead projects past it.
4. **OVERSPEED** — usable RPM `≥ maxRpm`.
5. **RPM_SIGNAL_LOST** — while fueled: in STARTING, pulse-recency only (so ignition
   EMI classifying NOISY doesn't false-abort a light-off); in IDLING/OPERATING, no
   pulse within `FUELED_RPM_LOSS_TIMEOUT_MS` (400 ms → fast flameout cut), OR a
   NOISY-but-present signal sustained ≥ `RPM_NOISY_ABORT_MS` (300 ms debounce, so a
   one-window EMI blip can't shut down a healthy engine). Suppressed for one
   loss-timeout after any `resetRpmStats()` so a stats reset can't read as loss.
   The same recency-not-NOISY logic is used by the SPINUP starter-prove checks.
6. **FLAMEOUT** — RPM `< flameoutRpm` after a 1.5 s grace **anchored to
   `runningSinceMs`** (first stable idle), so throttle toggles can't re-arm/mask it.

Other interlocks:
- `requestStop()` acts only in STARTING/IDLING/OPERATING (no ABORTED backdoor).
- `stage2Off()`/`off` in ABORTED, **and** in COOLDOWN while `cooldownAfterAbort` is
  true, only re-asserts safe outputs and does not transition to WAITING — it lets
  a post-abort cooldown finish into ABORTED instead of shortcutting past it;
  requires `clearabort` either way.
- `ignpulse` and `valve1/valve2 on` are blocked while EGT is hot
  (`fuelCommandBlockedByHotEgt`); `starttest` (starter only) stays allowed. The
  Test Wizard's `test ign`/`test starter_ign`/`test valve1`/`test valve2` apply the
  same hot-EGT guard (`test starter` is exempt, same reasoning).
- All outputs OFF on boot; ESC held at 1000 µs during arm.

---

## 🌐 Web UI (SoftAP)

- SSID `ECU_TestV1`, password `admin1234` (**weak default — change `WEB_PASS`
  before live use**; anyone on the AP can arm/start via `/cmd`), IP `192.168.4.1`.
- Routes: `/` (dashboard), `/api` (JSON status, `?act=0` when tab hidden so a
  walked-away session times out instead of keeping the watchdog alive), `/cmd?c=...`
  (runs `handleCommand`, same interlocks as Serial).
- Dashboard: status cards, controls, **Test Wizard**, **Tune quick set** and
  **Starter & Fuel PWM** panels whose inputs **auto-populate from live config**
  (so clicking Set can't silently change a limit), **Starter Manual Test**, event log.
- `webStatusJson()` builds the payload by hand (no ArduinoJson); `jsonEscape()`
  escapes `"` `\` and all control chars.

---

## 💾 SD Card Logging

- `sdLogEvent()` snapshots a CSV line and queues it (ring buffer, drop-oldest); the
  **blocking** `SD.open/println/close` happens in `flushSdEventQueue()` and
  `updateSdTelemetry()` late in the loop, after safety checks.
- **Backoff**: after 5 consecutive write failures `sdOk` is cleared so a pulled card
  stops blocking the control loop every cycle (re-enable requires reboot).
- Telemetry ~2 lines/s while active; CSV columns include time, mode, stage, EGT,
  gradient, RPM, fuel target, pump/start µs, ign, valves, throttle, abort reason.

---

## ✅ Test Wizard / Checklist

Nine tests (`test egt|rpm_noise|ign|starter|starter_ign|valve1|valve2|pump|kill`),
results `TEST_NOT_RUN/RUNNING/PASS/FAIL`. Optionally required before `startidle`
(`set checklist on/off`). Timed tests auto-off; `beginAutoIdle()` cancels any active
test so a countdown can't fire mid-start.

---

## 🎮 Serial / Web Commands (selected)

```
help | status | showcfg | rpmreset | stop | off
arm2 | autostart on/off | startidle | clearabort [force]
rpmdetail [on|off]
ignpulse <ms> | starttest <us> <ms> | pumptest <us> [ms]      (arm2, WAITING/ABORTED; EGT-hot blocked where fuel/ign)
valve1 on/off | valve2 on/off                                 (auto-off 10s; EGT-hot blocked)
test <name> | checklist | resetcheck | confirmkill | set checklist on/off
set intro/idleus/maxus/pumptestus <us>                        (WAITING/ABORTED only)
set purgeus/spinus/assistus <us>   (1000..1500)               (WAITING/ABORTED only)
set idlerpm/maxrpm/rpmtol <rpm> | set maxegt <C> | set maxgrad <C/s>   (WAITING/ABORTED only)
set acceltoidlems/cooldownms/cooltarget/coolstarter ...
set accelms/decelms/lowaccelms/lowdecelms | set throttle <0..100>
set commtimeout <ms> | set commwatchdog on/off
set rpmfilter <us> | set rpmedge rising|falling | set ppr 1|2  (ppr: WAITING/ABORTED only, rescales live RPM)
set egtstart dry|strict | set drystartms <ms>
```

---

## 🔌 Status LED (GPIO 2, active-low)

| Pattern | Meaning |
|---|---|
| Very fast | Component test running |
| Fast | Abort/error |
| Quick (~200 ms toggle) | Armed |
| Solid | Starting / running |
| Medium | Idle stable |
| Faster | Cooldown |
| Slow heartbeat | Waiting |

---

## 🐛 Debugging Tips

- **RPM quality**: `rpmdetail on` → want rejectPct <5%, jitter <15%, NOISE=CLEAN.
  A value pinned regardless of PWM ⇒ input frequency isn't changing (EMI at the
  fixed 50 Hz PWM, or a current-limited motor) — see the DSO152 section of
  `COMMISSIONING_GUIDE.md`.
- **EGT**: NaN/fault → check thermocouple + SPI; `egtFaultString()` decodes faults.
- **Fuel flow**: `pumptest`, compare SD `pump_us` against `kPumpMap`.
- **Starter torque**: `starttest`; tune `set purgeus/spinus/assistus`.

---

**Document Version**: 1.1
**Last Updated**: 2026-07-18
**Firmware**: ECU_TestV1_EGT_DRY_START_PATCH (raw-LEDC PWM, runtime-tunable, no kick)

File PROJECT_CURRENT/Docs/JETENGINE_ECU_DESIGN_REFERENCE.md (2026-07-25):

# Tài Liệu Tham Khảo Thiết Kế ECU Động Cơ Phản Lực (Enjet E86)

## Tổng Quan Dự Án

Tự chế hệ thống ECU (Engine Control Unit) cho động cơ phản lực mini **Enjet E86** — một thử thách lớn về cả phần cứng lẫn lập trình phần mềm. Động cơ này quay tối đa **152.000 RPM** và nhiệt độ buồng đốt có thể vượt quá **700°C**.

---

## 1. Khối Điều Khiển Motor Đề (Starter)

### 1.1 Vấn Đề Khởi Động Hiện Tại

Mạch ECU hiện tại gặp vấn đề khi khởi động:
- **Lỗi reset** xảy ra ở mức xung **~1465µs** (motor tải nặng từ cánh nén)
- **Nguyên nhân**: ESC BLHeli_S 30A được thiết kế tối ưu cho Drone (phản xạ nhanh, thay đổi tốc độ tức thì), nhưng khi tải là cánh nén (compressor) tải nặng tăng dần theo tốc độ → sốc dòng, sụt áp pin, reset vi điều khiển

### 1.2 Cải Thiện ESC Firmware

Cần nạp lại firmware BLHeli_S trên ESC đề bằng mạch CH340 + cáp 3 dây (GND, TXD, RXD):

| Tham số | Giá trị | Lý do |
|---|---|---|
| **Startup Power (Công suất khởi động)** | 0.125 – 0.25 (rất thấp) | Motor khởi động từ từ, không bị sốc dòng |
| **Motor Timing** | High | Giữ từ trường tối ưu khi tốc độ thấp |
| **Acceleration** | Slope Medium–High | Tăng ga nhẹ nhàng thay vì bốc |
| **Brake on Stop** | Enabled | Giữ motor dừng lại, tránh quay ngoài ý muốn |

### 1.3 Thuật Toán Tăng Xung PWM (Ramping Log) Trong Firmware ECU

**Bắt buộc**: Không được cho xung PWM nhảy thẳng từ 1000µs lên 1450µs — phải tăng dần từng bước nhỏ:

```
Ví dụ: Tăng mượt từ 1000µs → 1450µs
  Mỗi 10 ms: +1µs
  → Thời gian tổng: (1450 - 1000) × 10 = 4500 ms = 4.5 giây
  
Hoặc thậm chí chậm hơn nữa:
  Mỗi 20 ms: +1µs → 9 giây để lên tới 1450µs
```

**Lợi ích**:
- Motor có thời gian để **thắng lực cản cánh nén khí**
- Dòng điện tăng dần → không sốc, không sụt áp
- Pin cấp nguồn ổn định, vi điều khiển không reset

**Pseudocode**:
```cpp
void startMotor() {
  unsigned long lastStep = millis();
  int targetUs = 1450;
  int currentUs = 1000;
  
  while (currentUs < targetUs) {
    unsigned long now = millis();
    if (now - lastStep >= 10) {  // Mỗi 10ms tăng 1us
      currentUs++;
      escWriteUs(currentUs);
      lastStep = now;
    }
  }
}
```

---

## 2. Các Khối Cảm Biến Bắt Buộc Trên Mạch ECU

### 2.1 Khối Đo Tốc Độ Vòng Quay (RPM Sensor)

**Phần cứng**:
- Loại cảm biến: **Cảm biến từ trường (Hall effect)** hoặc **cảm biến quang học (Infrared)**
- Vị trí đặt: **Mũi động cơ** (phía trước cánh nén)
- Phương pháp: Đếm số vòng quay (nam châm/vạch sơn trên trục)
- **Mạch xử lý hiện tại**: KMZ10A (AMR) + INA826 (khuếch đại) + LMV358 (offset/gain) + LMV393 (comparator) → GPIO33

**Nhiệm vụ trong ECU**:
1. **Đo RPM liên tục** = cơ sở feedback cho các quyết định điều khiển
2. **Điểm chuyển tiếp động cơ**:
   - Khi RPM đạt **~30.000 RPM** → buồng đốt đã bắt lửa tự duy trì
   - **Ngắt hoàn toàn xung cấp cho motor đề** (ESC nhận 1000µs = 0% throttle)
   - Kích hoạt **ly hợp một chiều** tự nhả (freewheel) → động cơ tự vận hành độc lập
3. **Giám sát an toàn**:
   - Nếu RPM không tăng sau 5–10 giây khởi động → **fail to ignite** → tắt toàn bộ

### 2.2 Khối Đo Nhiệt Độ Buồng Đốt (EGT - Exhaust Gas Temperature)

**Phần cứng**:
- Loại cảm biến: **Nhiệt điện cặp loại K (Thermocouple Type K)**
- Phạm vi: 0–1300°C
- IC khuếch đại: **MAX6675** hoặc **MAX31855** (output SPI/I2C)
- Vị trí: Ống xả động cơ, gần buồng đốt (vị trí có nhiệt độ cao nhất)

**Nhiệm vụ trong ECU**:
1. **Xác nhận bắt lửa thành công**:
   - Khi mở van nhiên liệu mồi (Bước 3), cảm biến EGT phải báo nhiệt độ tăng lên (>150°C) trong 2–3 giây
   - Nếu không → **tắt toàn bộ**, báo lỗi "Fail to Ignite"
2. **Giám sát Over-Temperature**:
   - Nếu EGT vượt quá **850°C** → **tắt bơm dầu ngay**, giảm tốc độ động cơ
   - Nếu vượt quá **900°C** → **shutdown khẩn cấp** để tránh hủy động cơ
3. **Tối ưu hiệu suất**:
   - Giữ EGT ở **vùng tối ưu 750–820°C** bằng cách điều chỉnh tốc độ bơm dầu

---

## 3. Khối Điều Khiển Bơm Nhiên Liệu (Fuel Pump) và Van Solenoid

### 3.1 Bơm Nhiên Liệu (Fuel Pump)

**Thông số**:
- Loại: Motor brushed (chổi than) nhỏ + hộp số giảm tốc
- Nhiên liệu: Kerosene, Diesel, hoặc Jet-A1
- Điều khiển: **Xung PWM** (tốc độ bơm ∝ duty cycle PWM)

**Mạch điều khiển trên ECU**:
- **Cầu H (H-bridge)** hoặc **Mosfet** chịu dòng cao (≥ 30A)
- **GPIO từ ESP32** → Mosfet → Motor bơm
- Đo dòng bơm: Có cảm biến dòng (Current Sensor) tùy chọn để báo hiệu tắc dầu

**Thuật toán cấp dầu (Fuel Mapping)**:
```
Tốc độ bơm dầu (%) = f(RPM)
  
Vùng tua thấp (0 – 10.000 RPM):
  Bơm dầu rất ít (0–5%), tránh bị nghẹn
  
Vùng tua trung (10.000 – 30.000 RPM):
  Tăng tuyến tính theo RPM (5% → 50%)
  
Vùng tua cao (30.000 – 152.000 RPM):
  Bơm dầu cao (50% – 100%), tối ưu hoàn toàn
  
⚠️ Lưu ý: Nếu bơm quá nhiều khi tua còn thấp → động cơ bị nghẹn, lửa phụt
```

### 3.2 Cảm Biến Lưu Lượng Nhiên Liệu (Fuel Flow Sensor) — Closed-Loop Feedback

**Phần cứng**:
- Loại cảm biến: **ZJTM-04A-1.2** — turbine flow sensor dùng Hall effect (nguyên lý giống KMZ10A RPM: bánh turbine quay theo dòng chảy, nam châm trên turbine tạo xung mỗi vòng qua cảm biến Hall)
- Điện áp hoạt động: **3.5–24VDC**
- Ngõ ra: **NPN Pulse** (open-collector — bắt buộc phải có điện trở pull-up ngoài, xem sơ đồ dưới)
- Lưu lượng đo được: **0.05–1.5 L/phút**
- Vị trí lắp: **ngay sau bơm nhiên liệu, trước van solenoid dầu chính** — đo lưu lượng thực tế đã bơm ra, không phải suy đoán từ duty cycle PWM

**Dải tần số xung thực tế** (tính theo công thức hiệu chuẩn, xem bên dưới):
```
Tại Q_min = 0.05 L/phút  →  F = 190×0.05 − 5 = 4.5 Hz
Tại Q_max = 1.5  L/phút  →  F = 190×1.5  − 5 = 280 Hz

→ Dải tần số hoạt động: ~4.5 Hz – 280 Hz (tỷ lệ ~62 lần)
```

**Công thức hiệu chuẩn**:
```
F = 190 × Q − 5        (F: tần số Hz, Q: lưu lượng L/phút)

Suy ra dùng cho firmware:
Q = (F + 5) / 190

Số hạng −5: ngưỡng chết (dead-zone offset) — turbine cần lưu lượng tối
thiểu để thắng ma sát vòng bi trước khi bắt đầu quay, nên ở lưu lượng
rất thấp tần số đo được lệch khỏi quan hệ tuyến tính lý thuyết.
```

**GPIO được chọn: `PIN_FLOW = GPIO34`** — input-only, không có pull-up/pull-down nội (khớp thiết kế pull-up ngoài), không xung đột với các chân đang dùng trong firmware chính (18, 5, 19, 33, 26, 25, 17, 16, 32, 22, 2, 13, 14, 23, 27).

**Sơ đồ điện** — tái sử dụng đúng pattern bảo vệ GPIO đã dùng cho RPM_OUT (R10 pull-up 10K + R2 series 1K + D1 TVS clamp 3.3V):

```
                    UBEC 5V
                       │
        ┌──────────────┼──────────────┐
        │              │              │
   ESP32 VCC     ZJTM-04A-1.2 VCC   R_pullup (10K)
                       │              │
                      GND            (nối vào đây)
                       │              │
                    OUT (NPN) ────────┘
                       │
                       ├──→ R_series (1K)
                       │         │
                       │         ├──→ D_TVS (3.3V) ──→ GND
                       │         │
                       │         ↓
                       │    GPIO34 (ESP32, input-only)
                       │
                      GND ──────────→ GND chung toàn mạch
```

**Vì sao cần đủ 3 linh kiện** (giống lý do áp dụng cho RPM_OUT → GPIO33):
- **R_pullup (10K)**: Ngõ ra NPN open-collector chỉ kéo được xuống GND (mức LOW) khi transistor dẫn; khi không dẫn, chân OUT thả nổi — bắt buộc điện trở kéo lên nguồn để có mức HIGH rõ ràng
- **R_series (1K) + D_TVS (3.3V)**: Sensor cấp nguồn 5V → mức HIGH trên OUT cũng ~5V, vượt quá 3.3V GPIO chịu được. R_series giới hạn dòng, D_TVS kẹp áp về 3.3V

⚠️ **Không cấp nguồn sensor từ 3.3V ESP32** — dưới ngưỡng tối thiểu 3.5V, sensor sẽ không hoạt động ổn định.

**Firmware — đo CHU KỲ giữa các xung (không đếm xung/cửa sổ cố định)**:

⚠️ Với dải tần **4.5–280 Hz** (chênh lệch ~62 lần giữa min/max), kiểu đếm xung trong cửa sổ cố định (ví dụ 200ms như dùng cho RPM tần số cao) **không phù hợp** — ở lưu lượng thấp (4.5Hz), cửa sổ 200ms chỉ bắt được 0–1 xung, độ phân giải quá thô và nhiễu số đếm rất lớn (sai số ±100% giữa các lần đo).

**Giải pháp đúng**: đo **thời gian giữa 2 xung liên tiếp** (period), rồi suy ra tần số tức thời `F = 1/period` — cách này cho độ phân giải tốt xuyên suốt cả dải tần thấp lẫn cao:

```cpp
#define PIN_FLOW 34   // input-only, external pull-up 10K (không dùng INPUT_PULLUP nội)

volatile unsigned long lastPulseUs = 0;
volatile unsigned long pulsePeriodUs = 0;   // thời gian giữa 2 xung gần nhất
volatile bool newPulse = false;

void IRAM_ATTR flowISR() {
  unsigned long now = micros();
  pulsePeriodUs = now - lastPulseUs;
  lastPulseUs = now;
  newPulse = true;
}

// Trong loop:
if (newPulse) {
  noInterrupts();
  unsigned long period = pulsePeriodUs;
  newPulse = false;
  interrupts();

  float freqHz = 1000000.0 / period;         // F = 1/T
  float flowLpm = (freqHz + 5.0) / 190.0;    // Q = (F+5)/190
}

// Timeout: nếu không có xung mới trong > 1s (tương ứng < ~0.02 L/phút)
// → coi như lưu lượng = 0 (bơm đã dừng hoặc tắc dầu)
if (micros() - lastPulseUs > 1000000UL) {
  flowLpm = 0;
}
```

Nên tái dùng cơ chế chống nhiễu (NOISE reject/debounce) đã có trong `TEST_STARTER.ino` cho RPM để loại bỏ xung giả do rung động cơ khí của turbine, nhưng lưu ý: do tần số ở đây thấp hơn nhiều so với RPM sensor, cần điều chỉnh ngưỡng debounce time cho phù hợp (period tối thiểu hợp lệ ≈ 1/280Hz ≈ 3.57ms — bất kỳ xung nào đến sớm hơn khoảng này nên bị loại bỏ như nhiễu).

**Nâng cấp vòng điều khiển bơm (Closed-Loop)**:
Với Q đo được thực tế, ECU có thể so sánh **Q_target(RPM)** (tra theo fuel-map ở Mục 3.1) với **Q_actual** rồi hiệu chỉnh PWM bơm bằng vòng điều khiển P/PI đơn giản — thay vì chỉ set PWM cố định theo RPM và giả định lưu lượng đúng như tính toán (open-loop). Đây là bước nâng cấp từ open-loop sang closed-loop thực sự cho hệ thống cấp dầu.

### 3.3 Van Solenoid (Solenoid Valve)

**Cần ít nhất 2 van**:

| Van | Chức năng | Điều khiển |
|-----|---|---|
| **Van mồi (Kero-glow valve)** | Đóng/mở dầu mồi (dầu nhớt bề mặt để bắt lửa dễ hơn) | On/Off từ GPIO |
| **Van dầu chính (Main fuel valve)** | Đóng/mở dầu chính khi khởi động thành công | On/Off từ GPIO |

**Timeline khởi động**:
- **0–3s**: Van mồi MỞ, van chính ĐÓNG
- **3–4s**: Van chính MỞ (sau khi xác nhận bắt lửa từ EGT)
- **Shutdown**: Cả 2 van ĐÓNG

---

## 4. Quy Trình Lập Trình Chu Trình Khởi Động (Start Sequence)

### 4.1 Sơ Đồ Tổng Quát

```
┌─────────────────────────────────────────────────────────────┐
│                    KHỞI ĐỘNG ĐỘNG CƠ PHẢN LỰC              │
└─────────────────────────────────────────────────────────────┘

Bước 1: GlowPlug / Pre-heat (3–5 giây)
  ├─ Bật điện trở sưởi (Glow plug)
  ├─ Làm nóng buồng mồi
  └─ Chuẩn bị điều kiện để dầu bắt lửa dễ dàng

Bước 2: Spin up / Motor Đề Quay (4–5 giây)
  ├─ Cấp xung PWM tăng dần: 1000µs → 1450µs (mỗi 10ms +1µs)
  ├─ Motor đề quay, tạo luồng gió mồi
  ├─ RPM tăng từ 0 → 10.000 RPM
  └─ Theo dõi: Nếu RPM không tăng → FAIL

Bước 3: Ignition / Mở Dầu Mồi (2–3 giây)
  ├─ Mở van dầu mồi (Solenoid valve)
  ├─ Dầu phun vào buồng mồi, bắt lửa từ glow plug
  ├─ Giám sát EGT: phải tăng lên > 150°C trong 2 giây
  └─ Nếu EGT không tăng → FAIL TO IGNITE

Bước 4: Ramp Up / Tăng Ga (10–15 giây)
  ├─ Motor đề tiếp tục nhận xung (tuy có mắc cáp dầu chính)
  ├─ Mở van dầu chính
  ├─ Tăng tốc độ bơm dầu dần dần (0% → 80%)
  ├─ RPM tăng từ 10.000 → 42.000 RPM (tua garanti Enjet E86)
  ├─ Giám sát EGT: giữ trong vùng 750–820°C
  └─ Quá 850°C → cắt bơm; quá 900°C → shutdown

Bước 5: Disconnect / Ngắt Motor Đề (khi RPM > 35.000)
  ├─ Ngắt hoàn toàn xung cấp cho ESC (1000µs = 0% throttle)
  ├─ Tắt điện trở sưởi (Glow plug)
  ├─ Động cơ chính thức tự vận hành (Sustained)
  └─ Chuyển sang chế độ control vòng lặp (closed-loop RPM + EGT)
```

### 4.2 Pseudocode Chu Trình Khởi Động

```cpp
enum StartState {
  IDLE,
  GLOWPLUG,        // Bước 1
  SPINUP,           // Bước 2
  IGNITION,         // Bước 3
  RAMPUP,           // Bước 4
  SUSTAINED,        // Bước 5
  FAIL
};

class StartSequence {
  StartState state = IDLE;
  unsigned long startTime = 0;
  
  void begin() {
    startTime = millis();
    state = GLOWPLUG;
    digitalWrite(GLOW_PIN, HIGH);  // Bật glow plug
  }
  
  void update() {
    unsigned long elapsed = millis() - startTime;
    
    switch (state) {
      case GLOWPLUG:  // 0–3000ms
        if (elapsed >= 3000) {
          state = SPINUP;
          startTime = millis();
          // Bắt đầu tăng xung motor đề từ 1000µs
        }
        break;
        
      case SPINUP:  // 0–4500ms (tăng từ 1000µs→1450µs)
        {
          int targetPwm = 1000 + (elapsed / 10);  // +1µs mỗi 10ms
          targetPwm = min(targetPwm, 1450);
          escWriteUs(targetPwm);
          
          if (getRpm() < 500 && elapsed > 2000) {
            // Motor không quay → FAIL
            state = FAIL;
            break;
          }
          
          if (targetPwm >= 1450) {
            state = IGNITION;
            startTime = millis();
            digitalWrite(FUEL_PRIME_PIN, HIGH);  // Mở van dầu mồi
          }
        }
        break;
        
      case IGNITION:  // 0–3000ms
        {
          float egtTemp = readEGT();
          
          if (egtTemp > 150.0) {
            // Bắt lửa thành công
            state = RAMPUP;
            startTime = millis();
            digitalWrite(FUEL_MAIN_PIN, HIGH);   // Mở van dầu chính
          } else if (elapsed > 3000) {
            // Không bắt lửa → FAIL
            state = FAIL;
          }
        }
        break;
        
      case RAMPUP:  // 0–15000ms
        {
          float egtTemp = readEGT();
          int rpm = getRpm();
          
          // Điều khiển tốc độ bơm dầu theo RPM
          int pumpPwm = map(rpm, 10000, 42000, 0, 255);
          pumpPwm = constrain(pumpPwm, 0, 255);
          analogWrite(PUMP_PWM_PIN, pumpPwm);
          
          // Giám sát EGT
          if (egtTemp > 850.0) {
            pumpPwm = 0;  // Cắt bơm
          } else if (egtTemp > 900.0) {
            state = FAIL;  // Shutdown
            break;
          }
          
          // Khi RPM vượt 35000, ngắt motor đề
          if (rpm > 35000) {
            state = SUSTAINED;
            startTime = millis();
            escWriteUs(1000);  // 0% throttle = ESC off
            digitalWrite(GLOW_PIN, LOW);  // Tắt glow plug
          }
        }
        break;
        
      case SUSTAINED:
        // Động cơ tự vận hành, chuyển sang closed-loop control
        // Giữ EGT trong 750–820°C bằng điều chỉnh bơm dầu/throttle
        break;
        
      case FAIL:
        // Dừng tất cả
        escWriteUs(1000);
        digitalWrite(GLOW_PIN, LOW);
        digitalWrite(FUEL_PRIME_PIN, LOW);
        digitalWrite(FUEL_MAIN_PIN, LOW);
        analogWrite(PUMP_PWM_PIN, 0);
        break;
    }
  }
};
```

### 4.3 Các Điểm Kiểm Tra An Toàn (Safety Checks)

| Điều kiện | Hành động | Mục đích |
|---|---|---|
| RPM không tăng sau 2s (Spinup) | → FAIL | Phát hiện motor đề bị tắc/hỏng |
| EGT không tăng sau 3s (Ignition) | → FAIL | Phát hiện lỗi bắt lửa |
| EGT > 850°C | Cắt bơm dầu | Tránh quá nóng |
| EGT > 900°C | Shutdown | Tránh cháy động cơ |
| RPM > 152.000 (quá tua) | Cắt bơm, giảm throttle | Tránh cánh nén bị quá tải |

---

## 5. Các Cải Thiện Phần Cứng Cảm Biến (Optional nhưng Khuyên Dùng)

### 5.1 Bộ Lọc Thông Thấp (Low-Pass Filter) Cho RPM Sensor

**Vấn đề**: Tín hiệu từ cảm biến RPM (KMZ10A) dễ bị nhiễu PWM của motor đề lập lên, gây double-pulse hoặc skip pulse.

**Giải pháp**: Thêm bộ lọc RC ngay sau INA826 (TP_INA_OUT):
```
INA826_OUT ──[R]──┬──TP_INA_OUT → (tầng offset/gain hiện tại)
                  │
                  [C]
                  │
                  GND
                  
Giá trị gợi ý: R = 10kΩ, C = 100nF → f_cắt ≈ 160Hz
(hoặc R = 4.7kΩ, C = 220nF → f_cắt ≈ 150Hz)
```

**Tần số cắt nên nằm giữa**:
- **Tần số PWM motor đề** (thường 1–20kHz)
- **Tần số tín hiệu RPM tối đa** (152.000 RPM × 1 cực / 60 ≈ 2.533kHz)

Lọc 2 tầng (cascade) sẽ tốt hơn 1 tầng → dốc suy giảm mạnh hơn.

### 5.2 Đi Dây Cảm Biến (Cabling Best Practice)

- **Dây SENSOR_P / SENSOR_N**: Dùng **twisted pair (xoắn đôi)**, không dùng dây thẳng song song
- **Tách xa dây nguồn / dây motor đề**: Cách nhau ≥ 10cm (giảm EMI)
- **Dùng shielding** nếu có thể (lưới kim loại quanh dây, nối earth tại 1 đầu)
- **Độ dài dây**: ≤ 1 mét từ cảm biến đến mạch ECU

---

## 6. Tóm Tắt Checklist Thiết Kế ECU

- [ ] **ESC firmware tuning**: Startup Power 0.125–0.25, Motor Timing High
- [ ] **Thuật toán ramping**: Tăng PWM dần (≥ 10ms/µs) thay vì nhảy đột ngột
- [ ] **RPM sensor**: Hoạt động ổn định, không có skip pulse
- [ ] **EGT sensor**: Kết nối MAX6675/MAX31855, đọc nhiệt độ chính xác
- [ ] **Solenoid valves (×2)**: Van mồi + van dầu chính
- [ ] **Fuel pump control**: PWM điều khiển tốc độ bơm theo RPM
- [ ] **Safety checks**: Fail to ignite, over-temp, over-rpm
- [ ] **Closed-loop control loop**: Giữ EGT ở vùng tối ưu 750–820°C

---

## 7. Tài Liệu Tham Khảo Bổ Sung

- **BLHeli_S firmware**: https://github.com/bitdump/BLHeli (cài đặt param cho startup)
- **Enjet E86 specifications**: RPM max 152.000, nhiệt độ max 700°C+
- **MAX6675/MAX31855 datasheet**: Thermocouple amplifier IC
- **KMZ10A AMR sensor datasheet**: Magnetoresistive sensor characteristics
- **ESP32 PWM/LEDC**: Điều khiển ESC, bơm dầu, solenoid qua GPIO/LEDC

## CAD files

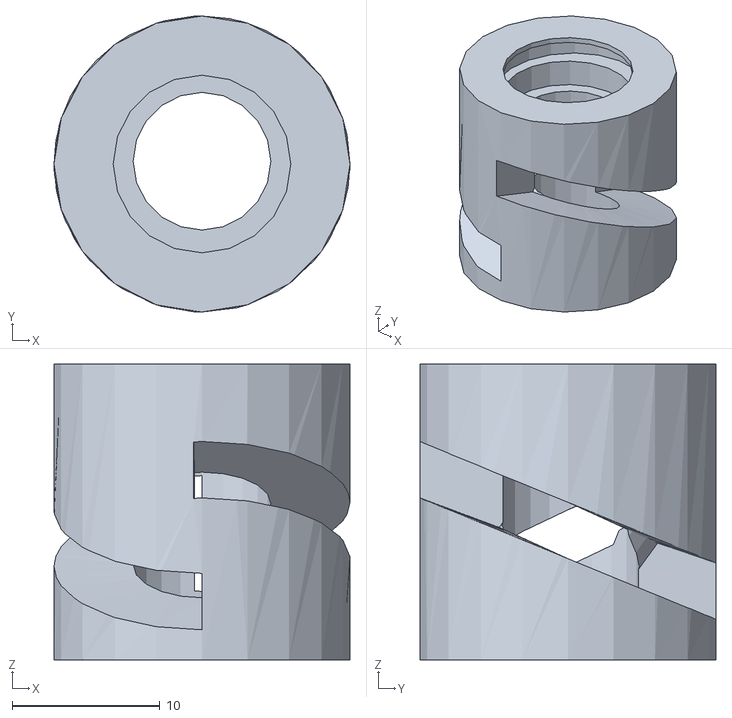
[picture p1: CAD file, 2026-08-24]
PROJECT_CURRENT/Hardware/3D Printable Files/Bendix Sleeve_Reinforced.stl
20.0 x 20.0 x 20.0

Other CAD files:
PROJECT_CURRENT/Hardware/3D Printable Files/Bendix Sleeve_10mm_NoSpring_Reinforced.stl
REFERENCES/Hardware/3D Printable Files/Bendix Sleeve_10.4mm_NoSpring_Reinforced.stl
PROJECT_CURRENT/Hardware/3D Printable Files/Bendix Sleeve_10.4mm_NoSpring_Reinforced.stl
REFERENCES/Hardware/3D Printable Files/Bendix Sleeve_10mm_NoSpring_Reinforced.stl
PROJECT_CURRENT/Hardware/3D Printable Files/Bendix Sleeve.stl
PROJECT_CURRENT/Hardware/3D Printable Files/Brushless motor mount.stl
PROJECT_CURRENT/Hardware/3D Printable Files/Brushed motor mount.stl

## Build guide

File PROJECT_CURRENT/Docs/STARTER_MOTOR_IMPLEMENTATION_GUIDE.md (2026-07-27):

# Hướng Dẫn Triển Khai Khối Điều Khiển Motor Đề (Starter Motor)

## Mục Tiêu

Giải quyết triệt để **lỗi reset tại mức xung ~1465µs** của mạch ECU khi khởi động động cơ phản lực Enjet E86, bằng cách đồng bộ hóa **Phần cứng (Hardware)**, **Cài đặt ESC (Configuration)**, và **Phần mềm (Firmware Code)**.

---

## 1. Chuẩn Bị Phần Cứng (Hardware Setup)

### 1.1 Tách Rời Nguồn Điện (Power Isolation) — **BẮT BUỘC**

**Vấn đề gốc rễ**: Khi motor đề chạy ở tốc độ cao và chịu tải nặng (cánh nén), dòng điện tức thời có thể lên tới 30–50A. Nếu dùng chung pin 3S cho cả ESC lẫn vi điều khiển (Arduino/ESP32):
- Dây dẫn từ pin → ESC → GND chung với mạch vi điều khiển sẽ tạo **sụt áp (voltage droop)** hàng chục mV
- Vi điều khiển nhạy cảm với sụt áp, khi VDD xuống dưới ngưỡng brownout (~3V) → **reset**

**Giải pháp**:

| Thành phần | Cấu hình |
|---|---|
| **Pin LiPo 3S khởi động motor đề** | Cấp riêng cho ESC 30A |
| **Nguồn vi điều khiển** | BEC 5V từ pin 2S/3S khác HOẶC sạc dự phòng 5V USB riêng |
| **Nối chung GND** | ✅ Nối GND của ESC + GND của vi điều khiển cùng với pin (điểm tham chiếu chung) |
| **Không nối chung VDD** | ❌ Tuyệt đối không dùng chung pin 3S trực tiếp |

**Sơ đồ nối nguồn**:
```
Pin 3S (Motor)
  ├─ Dây (+) → ESC 30A (cực dương IN)
  ├─ Dây (-) → ESC GND (cực âm IN)
  └─ GND chung tới vi điều khiển

Pin 5V / BEC (Vi điều khiển)
  ├─ Dây 5V → Arduino/ESP32 VCC
  ├─ Dây GND → Arduino/ESP32 GND
  └─ GND chung tới pin motor (điểm tham chiếu duy nhất)

(Không có dây VDD trực tiếp từ pin 3S motor tới vi điều khiển)
```

### 1.2 Tụ Lọc Nguồn Lớn (Buffer Capacitor) — **KHUYẾN CÁO**

**Mục đích**: Bù áp tức thời khi dòng motor đột ngột tăng, ngăn sụt áp đột ngột.

**Thông số**:
- Loại: **Electrolytic capacitor**
- Dung lượng: **1000µF hoặc lớn hơn** (2200µF tốt nhất)
- Điện áp: **25V** trở lên (vì pin 3S → max ~12.6V)
- Vị trí: **Hàn song song ngay tại 2 cực vào (Âm/Dương) của ESC**

**Cách hàn**:
```
Pin 3S (+) ──────┬──→ ESC IN (+)
                 │
                [C] 1000µF / 25V
                 │
Pin 3S (-) ──────┴──→ ESC IN (-)
```

**Lưu ý an toàn**:
- Kiểm tra cực tính capacitor (+ và -)
- Để dây dẫn càng ngắn càng tốt (< 5cm)
- Không được hàn capacitor ngược cực → nổ

### 1.3 Mạch Lọc Nhiễu Nguồn DC (Power Noise Filter) — **KHUYẾN CÁO**

**Mục đích**: Lọc sạch và làm phẳng điện áp từ pin LiPo trước khi cấp cho UBEC, giảm ripple/noise do motor đề gây ra. Điều này bảo vệ vi điều khiển khỏi nhiễu PWM của motor.

**Thông số mạch**:
- **Loại**: Mạch lọc LC (LC Power Filter)
- **Điện áp hoạt động**: 0–50V DC
- **Dòng tối đa**: 4A
- **Công dụng**: Lọc sạch, làm phẳng điện áp, giảm ù rè, sôi nền

**Sơ đồ nối**:
```
Pin 3S LiPo (0-50V)
    ↓
[Mạch Lọc LC 0-50V 4A]  ← Làm sạch nguồn, giảm ripple
    ↓
UBEC 5V (ổn áp thành 5V)
    ↓
ESP32 VCC (nhận 5V sạch)
```

**Lợi ích**:
- Giảm nhiễu PWM từ motor đề ảnh hưởng đến ESP32
- Làm phẳng điện áp, tránh sụt áp đột ngột
- Bảo vệ UBEC và vi điều khiển khỏi spike điện áp

**Lưu ý**:
- Đặt mạch này **càng gần pin LiPo càng tốt** (dây vào ngắn)
- Màu sắc tụ điện có thể thay đổi theo đợt hàng → công năng không đổi
- Đảm bảo dòng chạy qua mạch không vượt 4A (không vấn đề cho ESP32 + UBEC, chỉ cần lưu ý khi có thêm thiết bị khác)

### 1.4 Mạch Gộp Dây CH340 (Để Cấu Hình ESC) — **CẦN CHUẨN BỊ**

⚠️ **Sửa lại so với hiểu ban đầu**: Chip trên ESC BLHeli_S giao tiếp qua **MỘT dây tín hiệu duy nhất** (1-wire, half-duplex) — **không phải 3 dây GND+TXD+RXD tách biệt**. Vì mạch CH340 là full-duplex (TX và RX riêng), cần **gộp chung TX và RX lại bằng 1 điện trở** để tạo giao tiếp 1 dây tương thích.

**Linh kiện cần**: 1 điện trở **1kΩ – 10kΩ**

**Sơ đồ đấu nối**:
```
       MẠCH USB TTL CH340
     +-------------------+
     |                   |
     |               TX  |------+
     |                   |      |
     |                   |    [ĐIỆN TRỞ] (1k – 10k Ohm)
     |                   |      |
     |               RX  |------+======> CẮM VÀO dây TÍN HIỆU (Trắng/Vàng)
     |                   |               của rắc cắm nhỏ trên ESC
     |                   |
     |              GND  |==============> CẮM VÀO dây MÁT (Đen/Nâu)
     +-------------------+               của rắc cắm nhỏ trên ESC

       PIN LIPO 3S                      ESC BLHeli_S 30A
     +--------------+                  +------------------+
     |   Cực Dương  |(+)==============>(+) Dây Nguồn Đỏ    |
     |   Cực Âm     |(-)==============>(-) Dây Nguồn Đen   |
     +--------------+                  +------------------+
```

**⚠️ 3 Lưu Ý Sống Còn Khi Đấu Nối**:

1. **Vị trí lấy dây tín hiệu**: Dây Trắng (hoặc Vàng) và dây Đen (hoặc Nâu) là 2 sợi nhỏ nằm trên **rắc cắm 3 chân** (rắc cắm vào mạch nhận/mạch test servo) — **không phải dây động lực to nối vào motor**.
2. **Dây đỏ nhỏ trên rắc 3 chân (dây BEC 5V)**: **Để trống, tuyệt đối không cắm vào mạch CH340** — tránh xung đột điện áp làm cháy cổng USB máy tính.
3. **Trình tự cấp nguồn** (bắt buộc đúng thứ tự): Cắm mạch CH340 vào máy tính trước → Mở BLHeliSuite → Bấm Connect → **Sau cùng mới cắm Pin 3S vào ESC** để cấp nguồn cao áp cho chip chạy, rồi mới bấm Read Setup.

Dùng phần mềm **BLHeliSuite** (bản dành cho chip Silabs/Atmel, **không dùng bản BLHeliSuite32**) để đọc/ghi cấu hình ESC.

---

## 2. Cài Đặt ESC BLHeli_S (Configuration)

### 2.1 Chuẩn Bị Mạch Nạp Gộp Chân (1-Wire)

Xem **Mục 1.4** để đấu dây (điện trở gộp TX-RX của CH340, nối vào dây tín hiệu + GND của ESC).

⚠️ **CỰC KỲ QUAN TRỌNG**: **Tháo hoàn toàn bánh răng/củ đề ra khỏi motor** để motor chạy trơn (không tải), đảm bảo an toàn nếu motor quay đột ngột. **Chưa cắm pin vào ESC** ở bước này.

### 2.2 Thao Tác Trên Phần Mềm BLHeliSuite

**Bước 1**: Cắm mạch CH340 vào máy tính qua cổng USB.

**Bước 2**: Tải và mở phần mềm **BLHeliSuite** (dùng bản dành cho chip **Silabs/Atmel**, không dùng bản BLHeliSuite32) — https://github.com/bitdump/BLHeli

**Bước 3**: Trên thanh menu, bấm **Select ATMEL / SILABS Interface**.

**Bước 4**: Chọn dòng **SILABS BLHeli Bootloader (USB/Com)** (thường ở vị trí số 4 hoặc 6).

**Bước 5**: Ở góc dưới bên trái, tại ô **Port**, chọn đúng cổng COM của mạch CH340. Phần **Baud** để mặc định (19200 hoặc 9600).

**Bước 6**: Bấm nút **Connect** ở góc dưới bên trái — nút sẽ chuyển sang trạng thái chờ cấp nguồn.

### 2.3 Cấp Nguồn Và Đọc Thông Số (Read Setup)

**Bước 1**: Cắm nguồn Pin 3S vào ESC (**chỉ sau khi đã bấm Connect ở Bước 2.2.6**). Motor sẽ phát tiếng tít tít báo hiệu đã có nguồn nuôi chip.

**Bước 2**: Bấm nút **Read Setup** (cạnh nút Connect).

**Bước 3**: Nếu đấu dây đúng, phần mềm hiển thị thông báo đã nhận diện ESC (vd: "Found ESC #1..."). Bấm **OK**.

**Bước 4**: Sửa 3 thông số quan trọng — xem **Mục 2.4** dưới đây.

**Bước 5**: Bấm **Write Setup** ở góc dưới để lưu cấu hình mới vào chip ESC.

**Bước 6**: Bấm **Disconnect** và **rút pin ra**.

### 2.4 Ba Thông Số Cần Chỉnh Sửa Trong BLHeliSuite

Sau khi đọc firmware ESC lên, bạn sẽ thấy cửa sổ **Settings** chứa hàng chục tham số. Chỉ cần sửa **3 thông số sau**:

#### Thông Số 1: **Startup Power** (Công suất khởi động)
| Hiện tại | Thay đổi thành | Lý do |
|---|---|---|
| **0.5 – 1.0** (mặc định drone) | **0.125 – 0.25** | Giảm dòng khởi động, motor không bị "búng" mạnh → tránh sốc dòng, sụt áp |

**Chi tiết**:
- Giá trị thấp = dòng khởi động thấp = tăng tốc từ từ
- Giá trị cao = dòng khởi động cao = tăng tốc nhanh (lý tưởng cho drone nhẹ, nhưng tai hại cho tải nặng)

**Đề xuất**: Chọn **0.125** (thấp nhất) để test an toàn lần đầu. Nếu motor khởi động quá yếu, tăng dần lên 0.25 / 0.375 / 0.5.

#### Thông Số 2: **Motor Timing** (Góc đánh lửa / Phase Advance)
| Hiện tại | Thay đổi thành | Lý do |
|---|---|---|
| **Medium** | **High** | Chip Silabs tính toán pha chuẩn hơn khi motor kéo tải nặng → chống desync |

**Chi tiết**:
- **Low**: Phase lag lớn → thiếu mô-men xoắn khi tua thấp
- **Medium**: Cân bằng (mặc định drone)
- **High**: Advance chuẩn xác hơn → mô-men xoắn tốt ở tua thấp (lý tưởng cho starter)

**Đề xuất**: Để **High** để có sức mạnh tối đa khi khởi động.

#### Thông Số 3: **Low RPM Power Protect** (Bảo vệ tua thấp)
| Hiện tại | Thay đổi thành | Lý do |
|---|---|---|
| **Enabled** (mặc định) | **Disabled** (Tắt) | Tắt tính năng này để motor có đủ lực kéo cánh nén khí ở tua thấp |

**Chi tiết**:
- **Enabled** (mặc định): Nếu motor cảm thấy quay nặng ở tua thấp, ESC sẽ tự ngắt để bảo vệ. Điều này **rất hữu ích cho drone** (tránh motor bị khỏa quá tức thì), nhưng **tai hại cho motor đề** (ngắt đột ngột → motor không thể kéo cánh nén).
- **Disabled**: Motor sẽ cố gắng đẩy mạnh nhất có thể, miễn là dòng không vượt giới hạn firmware.

**Đề xuất**: **Disabled** (Tắt) để motor đề có full power.

### 2.5 Các Thông Số Khác (Giữ Mặc Định)

| Thông số | Giữ nguyên | Ghi chú |
|---|-----|----|
| Max Throttle | 2000µs | Chuẩn |
| Min Throttle | 1000µs | Chuẩn |
| Motor Poles | (Tùy motor đề) | Không thay đổi |
| Battery Type | LiPo (3S) | OK |
| Braking | Enabled hoặc Disabled | Tùy chọn |

### 2.6 Cân Chỉnh Hành Trình Ga (Calibrate ESC) Bằng Tay

Sau khi đã nạp cấu hình chống reset (Mục 2.4), cần thêm bước này để ESC hiểu chính xác mức xung **thấp nhất (1000µs)** và **cao nhất (2000µs)** phát ra từ mạch Arduino/ESP32 — nếu bỏ qua bước này, ESC có thể hiểu sai dải hành trình ga và phản ứng không tuyến tính hoặc không đúng dải PWM mà firmware ECU đang phát.

**Bước 1**: Rút nguồn pin ra khỏi ESC.

**Bước 2**: Trên mạch Arduino/ESP32, nạp đoạn code phát xung ở mức **tối đa kịch ga (2000µs) liên tục**.

**Bước 3**: Cắm nguồn Pin 3S vào ESC → motor phát vài tiếng tít tít báo hiệu đã nhận mức ga cao nhất.

**Bước 4**: **Ngay lập tức (trong vòng 1–2 giây)**, chỉnh code hoặc gạt cần để hạ xung về mức **tối thiểu (1000µs)**.

**Bước 5**: Motor kêu một đoạn nhạc chào ngắn báo hiệu đã lưu xong hành trình ga mới.

Từ lúc này, hành trình ga của ESC đã được đồng bộ chuẩn xác với mạch ECU tự chế.

**✅ Đã tích hợp sẵn vào firmware chính** (`ECU_TestV1_EGT_DRY_START_PATCH.ino`) — không cần nạp riêng 1 sketch bench cho bước này nữa:
- Lệnh Serial/API: `esccal start` (phát MAX 2000µs trên PUMP+STARTER, tự động hạ về MIN 1000µs sau 5 giây — non-blocking, không dùng `delay()` để không treo vòng lặp ECU) và `esccal cancel` (hủy giữa chừng, về an toàn ngay)
- Nút bấm trên **Web UI, tab Settings**: "⚠️ Bắt Đầu Cân Chỉnh ESC" (có hộp thoại xác nhận nhắc tháo bánh răng/củ đề trước) và "Hủy / Về An Toàn"
- Chỉ hoạt động khi ECU đang ở mode **WAITING/ABORTED** (giống các lệnh test tay khác), van nhiên liệu không mở trong lúc chạy lệnh này (chỉ hiệu chỉnh dải PWM, không phun dầu thật)

---

## 3. Lập Trình Phần Mềm (Firmware Code)

### 3.1 Nguyên Tắc: Thuật Toán Ramping (Tăng Ga Mịn)

**Vấn đề**: Nếu code ghi `escWriteUs(1450)` một cách trực tiếp (nhảy từ 1000µs → 1450µs tức thì), dòng motor sẽ tăng từ 0A → 30–50A trong **vài milisecond**, gây sốc dòng → sụt áp → reset.

**Giải pháp**: Tăng xung **từng chút một** theo thời gian, để dòng tăng dần mà pin kịp cấp.

**Công thức**:
```
Thời gian để tăng từ A µs → B µs với bước ∆ µs mỗi T ms:

Số bước = (B - A) / ∆
Thời gian tổng = số bước × T

Ví dụ:
  Tăng từ 1000µs → 1450µs
  Bước tăng: 1µs
  Khoảng thời gian: 10ms
  → Số bước = 450 / 1 = 450
  → Thời gian = 450 × 10ms = 4500ms = 4.5 giây
```

### 3.2 Đoạn Code Triển Khai

Dưới đây là code Arduino/ESP32 để test thuật toán ramping:

#### **Phiên Bản 1: Dùng Servo library (Đơn giản)**

```cpp
#include <Servo.h>

Servo starterMotor;
int currentPWM = 1000;      // Giá trị PWM hiện tại (đơn vị: µs)
int targetPWM = 1450;       // Giá trị PWM đích muốn thử
unsigned long previousMillis = 0;
const int rampInterval = 10; // Cứ mỗi 10ms thì tăng xung 1 lần (1µs)

void setup() {
  Serial.begin(115200);
  
  // Gắn servo vào chân GPIO (ví dụ: chân 9 trên Arduino, GPIO 27 trên ESP32)
  starterMotor.attach(9);
  
  // Khởi tạo ESC ở mức 0% ga (1000µs)
  starterMotor.writeMicroseconds(1000);
  Serial.println("ESC initialized at 1000us (0% throttle)");
  
  // Chờ ESC nhận tay ga (~3 giây, ESC phát tiếng nhạc chào)
  delay(3000);
  Serial.println("Ready to ramp up...");
}

void loop() {
  unsigned long currentMillis = millis();
  
  // Kiểm tra khoảng thời gian để tăng xung
  if (currentMillis - previousMillis >= rampInterval) {
    previousMillis = currentMillis;
    
    // Nếu chưa đạt target, tăng thêm 1µs
    if (currentPWM < targetPWM) {
      currentPWM++;
      starterMotor.writeMicroseconds(currentPWM);
      
      // In ra Serial để theo dõi
      Serial.print("PWM: ");
      Serial.print(currentPWM);
      Serial.println("us");
    } else {
      // Đã đạt target, giữ nguyên
      Serial.println("Target reached! Holding at ");
      Serial.println(targetPWM);
      
      // Giữ mãi mãi (hoặc set timeout để dừng)
      while (true) {
        delay(100);
      }
    }
  }
}
```

#### **Phiên Bản 2: Dùng LEDC (ESP32 native, không cần Servo library)**

```cpp
// ESP32 LEDC PWM
const int MOTOR_PIN = 27;        // Chân GPIO điều khiển motor
const int LEDC_CHANNEL = 0;
const int LEDC_FREQ = 50;        // 50Hz cho servo/ESC
const int LEDC_RES = 16;         // 16-bit resolution
const int PWM_MIN = 1000;        // µs
const int PWM_MAX = 2000;        // µs

int currentPWM = 1000;
int targetPWM = 1450;
unsigned long previousMillis = 0;
const int rampInterval = 10;     // ms

void setup() {
  Serial.begin(115200);
  
  // Cấu hình LEDC
  ledcAttach(MOTOR_PIN, LEDC_FREQ, LEDC_RES);
  
  // Khởi tạo ESC
  writePWM(1000);
  Serial.println("ESC initialized at 1000us");
  
  delay(3000);
  Serial.println("Ready to ramp up...");
}

void loop() {
  unsigned long currentMillis = millis();
  
  if (currentMillis - previousMillis >= rampInterval) {
    previousMillis = currentMillis;
    
    if (currentPWM < targetPWM) {
      currentPWM++;
      writePWM(currentPWM);
      
      Serial.print("PWM: ");
      Serial.print(currentPWM);
      Serial.println("us");
    } else {
      Serial.print("Target reached at ");
      Serial.println(targetPWM);
      delay(1000000);  // Dừng forever
    }
  }
}

// Hàm chuyển đổi µs → duty cycle LEDC
void writePWM(int microSeconds) {
  // LEDC 50Hz → 1 chu kỳ = 20ms = 20000µs
  // duty = (microSeconds / 20000) × 2^16
  int duty = map(microSeconds, 1000, 2000, 800, 1600);  // Tương ứng với 5% – 8% duty
  ledcWrite(LEDC_CHANNEL, duty);
}
```

### 3.3 Hướng Dẫn Test Code

1. **Sửa giá trị `targetPWM`** nếu cần:
   - Lần 1: Test với `targetPWM = 1200` (an toàn, tốc độ thấp)
   - Lần 2: `targetPWM = 1300`
   - Lần 3: `targetPWM = 1400`
   - Lần 4: `targetPWM = 1450` (mục tiêu)

2. **Cấp nguồn**: 
   - Pin 3S cho ESC
   - BEC 5V cho Arduino/ESP32
   - Cắm cáp từ GPIO (Arduino pin 9 / ESP32 GPIO 27) vào chân tín hiệu ESC

3. **Mở Serial Monitor** ở 115200 baud → xem in log PWM

4. **Quan sát**:
   - Motor quay hay không?
   - RPM có tăng từ từ không?
   - Có bị reset không?
   - Nếu không reset ở 1450µs → **thành công!**

### 3.4 Nếu Vẫn Gặp Lỗi Reset

| Triệu chứng | Nguyên nhân | Cách khắc phục |
|---|---|---|
| Motor không quay | ESC không nhận lệnh | Kiểm tra cáp nối GPIO → ESC, kiểm tra ESC đã khởi tạo thành công |
| Motor quay rồi dừng + reset | Sụt áp → vi điều khiển reset | Kiểm tra tụ lọc 1000µF đã hàn chưa? Kiểm tra pin 3S có đủ dung lượng không? |
| Reset ở tua cao nhất | Dòng quá lớn | Giảm `targetPWM` xuống, hoặc tăng `rampInterval` (chậm hơn) |
| Motor khởi động rất yếu | Startup Power ESC quá thấp | Tăng từ 0.125 lên 0.25 / 0.375 trong BLHeliSuite |

---

## 4. Checklist Triển Khai Chi Tiết

### ✅ Giai Đoạn 1: Chuẩn Bị Phần Cứng
- [ ] Chuẩn bị 2 pin LiPo riêng (1 cho ESC motor, 1 cho BEC vi điều khiển)
- [ ] Hàn capacitor 1000µF/25V song song vào 2 cực vào ESC
- [ ] **Nối Mạch Lọc Nhiễu DC 0-50V 4A**: Pin → Mạch lọc → UBEC 5V → ESP32
- [ ] Nối dây GND chung giữa pin motor + pin BEC + vi điều khiển (điểm tham chiếu duy nhất)
- [ ] Chuẩn bị mạch CH340 với jumper 3.3V

### ✅ Giai Đoạn 2: Cấu Hình ESC
- [ ] Tháo bánh răng/củ đề khỏi motor (an toàn khi test)
- [ ] Hàn điện trở 1k–10k gộp chân TX-RX trên mạch CH340
- [ ] Đấu dây tín hiệu (Trắng/Vàng) + GND (Đen/Nâu) từ rắc 3 chân ESC vào CH340 — **không đấu dây BEC 5V (đỏ)**
- [ ] Tải phần mềm BLHeliSuite (bản Silabs/Atmel, không dùng BLHeliSuite32)
- [ ] Cắm CH340 vào máy tính → chọn Select ATMEL/SILABS Interface → SILABS BLHeli Bootloader (USB/Com) → chọn cổng COM → bấm **Connect**
- [ ] **Sau đó mới** cắm Pin 3S vào ESC (đúng thứ tự: Connect trước, cấp nguồn sau)
- [ ] Bấm **Read Setup** → xác nhận nhận diện ESC thành công
- [ ] **Sửa 3 thông số**:
  - [ ] Startup Power: **0.125 – 0.25**
  - [ ] Motor Timing: **High**
  - [ ] Low RPM Power Protect: **Disabled (Tắt)**
- [ ] Bấm **Write Setup** → nghe tiếng nhạc chào → Disconnect → rút pin
- [ ] **Cân chỉnh hành trình ga** (Mục 2.6): phát 2000µs liên tục khi cấp nguồn, hạ về 1000µs trong 1–2 giây, nghe nhạc chào xác nhận lưu thành công

### ✅ Giai Đoạn 3: Viết & Test Code
- [ ] Chọn code Arduino hoặc LEDC (tùy vi điều khiển)
- [ ] Nạp vào Arduino/ESP32
- [ ] Mở Serial Monitor (115200 baud)
- [ ] **Test dần từ thấp lên cao**:
  - [ ] targetPWM = 1200 → không reset?
  - [ ] targetPWM = 1300 → không reset?
  - [ ] targetPWM = 1400 → không reset?
  - [ ] targetPWM = 1450 → không reset? ✅ **Mục tiêu đạt được!**

### ✅ Giai Đoạn 4: Tối Ưu (Optional)
- [ ] Giảm `rampInterval` (tăng tốc độ tăng xung) nếu 4.5 giây quá lâu
- [ ] Giảm `rampInterval` = tăng dòng nhanh hơn = kiểm tra độ ổn định pin
- [ ] Nếu vẫn ổn định → tốt!

---

## 5. Tài Liệu & Link Tham Khảo

- **BLHeliSuite**: https://github.com/bitdump/BLHeli
- **BLHeli_S Firmware Configuration**: https://blhelisuite.blogspot.com/ (blog chính thức)
- **Arduino Servo Library**: https://www.arduino.cc/reference/en/libraries/servo/
- **ESP32 LEDC**: https://docs.espressif.com/projects/esp-idf/en/latest/esp32/api-reference/peripherals/ledc.html
- **Pin Specs**: Loại LiPo 3S (11.1V nominal) + High discharge rate (30C+)

---

## 6. Ghi Chú Quan Trọng

⚠️ **An toàn điện**:
- Luôn kiểm tra cực tính pin trước khi cắm
- Không được sơ ý hạ dài dây dẫn (có thể gây chập nháp)
- Capacitor 1000µF có năng lượng → tắt pin trước khi tháo

⚠️ **Test tuần tự**:
- Không cố gắng nhảy thẳng lên 1450µs lần đầu
- Test từ 1100µs → 1150µs → 1200µs → ... từ từ
- Mỗi lần test cách nhau ít nhất 5–10 phút (để pin hạ nhiệt)

⚠️ **Motor Đề**:
- Motor đề của Enjet E86 thường là motor brushed DC nhỏ (không phải brushless)
- Nếu ESC của bạn là cho brushless, cần ESC khác hoặc chuyển đổi firmware (nếu ESC hỗ trợ)

---

## Kết Luận

Bằng cách kết hợp:
1. **Tách rời nguồn** (chống sụt áp)
2. **Tuning ESC** (Startup Power + Timing + Low RPM Protect)
3. **Code ramping mịn** (tăng dòng từ từ)

Bạn sẽ **loại bỏ triệt để lỗi reset ở 1465µs** và có một khối điều khiển motor đề ổn định, sẵn sàng cho giai đoạn khởi động động cơ phản lực tiếp theo.

Nếu vẫn gặp khó khăn ở bất kỳ bước nào, hãy báo với mình — chúng ta sẽ debug từng phần một! 🚀

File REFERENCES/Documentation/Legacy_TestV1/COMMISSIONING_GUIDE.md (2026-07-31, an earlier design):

# Hướng Dẫn Toàn Diện: Upload, Hiệu Chỉnh & Commissioning ECU

**Firmware**: `ECU_TestV1_EGT_DRY_START_PATCH.ino`
**Board**: ESP32 DevKit V1 / NodeMCU-32S
**Đối tượng**: Từ upload firmware lần đầu tới chạy thật có tăng throttle, đi từng bước an toàn.

> Nguyên tắc xuyên suốt: **không nhảy cóc bước**. Mỗi giai đoạn dưới phải
> PASS hết rồi mới sang giai đoạn kế tiếp. Nếu bất kỳ bước nào FAIL — dừng,
> tìm nguyên nhân, không ép qua bằng debug override.
>
> Tài liệu này gộp toàn bộ các hướng dẫn trước đây
> (Upload & Test, Pre-Engine Test, DSO152 RPM Calibration, Commissioning)
> thành **1 file duy nhất** để không phải lật qua nhiều tài liệu.
>
> **Điều khiển & test hoàn toàn qua Web UI (không cần terminal).** Kể từ bản
> hiện tại, mọi thao tác điều khiển, Test Wizard, manual test (starter / pump /
> glow / valve) và toàn bộ tham số tune (RPM, PWM, EGT, timing, cooldown,
> interlock) đều có nút/ô nhập trên giao diện web `http://192.168.4.1`
> (SoftAP `ECU_TestV1` / `admin1234`). Các lệnh Serial vẫn còn hoạt động như
> phương án dự phòng, nhưng không bắt buộc dùng.
>
> Giao diện web chia **4 tab**:
> - **▶ Run** — điều khiển (ARM / START IDLE / AutoStart / SOFT STOP / SAFE OFF /
>   CLEAR ABORT / RPM RESET), chế độ EGT, và các thẻ trạng thái chi tiết.
> - **🧪 Testing** — Test Wizard (9 bước + checklist) và Manual Actuator Test
>   **có thời lượng** (starter/pump chạy đúng số ms nhập vào rồi tự tắt, ignpulse
>   glow có giới hạn thời gian) — dùng để test nhanh, có kiểm soát thời gian.
> - **🔧 Manual** — điều khiển tay **giữ nguyên tới khi tự tắt** (không có thời
>   lượng): starter (`startmanual <us>`/`off`), pump (`pumpmanual <us>`/`off`,
>   tự mở Valve 1), glow (`ign on`/`off`), Valve 1, Valve 2 — kèm nút
>   **"🛑 SAFE OFF — TẮT HẾT NGAY"** và vài thẻ trạng thái (RPM/EGT/Starter/
>   Pump/IGN/Valve) ngay trên tab để không phải chuyển qua Run. Dùng khi cần
>   giữ 1 cơ cấu chạy liên tục để quan sát (đo dòng, đo nhiệt, canh chỉnh...).
> - **⚙ Settings** — toàn bộ tham số tune + lưu/nạp config, mục **"Advanced"**
>   (timing/cooldown/interlock) mở/gập được.
>
> Phía trên luôn hiển thị **2 đồng hồ (gauge) RPM & EGT** và dải chip trạng thái
> (MODE / STAGE / ARM / AUTO / NOISE / CHECK / ABORT) đổi màu theo trạng thái.
>
> **Lưu config vào thẻ SD (cấu hình 1 lần):** trong tab **Settings**, bấm
> **"💾 Lưu config vào SD"** để ghi toàn bộ tham số tune ra `/ECUCFG.TXT`. Lần
> sau bật máy, firmware **tự nạp lại** file này lúc boot (mọi giá trị được kẹp
> trong khoảng hợp lệ khi nạp). Nút **"↻ Nạp lại từ SD"** nạp lại ngay không cần
> khởi động lại. Vì an toàn, `autoStart`, throttle và web KHÔNG được lưu — luôn
> khởi động ở trạng thái an toàn. (Lệnh Serial tương đương: `savecfg` / `loadcfg`.)

---

## ⚠️ Cảnh Báo An Toàn Chung

- Luôn test trong không gian thoáng khí
- Tháo nhiên liệu ra khỏi hệ thống khi test điện tử/component
- Giữ khoảng cách an toàn khi động cơ/starter quay
- Có người thứ 2 giám sát khi test engine thực có nhiên liệu
- Chuẩn bị bình chữa cháy **CO2** gần tầm tay (không dùng bột khô)
- Kill switch vật lý (NC) phải lắp và test cơ học độc lập — không dựa vào firmware

---

## Yêu Cầu Trước Khi Bắt Đầu

### Hardware
- [ ] ESP32 DevKit V1 hoặc NodeMCU-32S
- [ ] Cáp USB (USB-A to Micro-USB)
- [ ] Máy tính có Arduino IDE
- [ ] MAX31855 Thermocouple Module + Thermocouple loại K
- [ ] RPM Sensor (KMZ10A AMR + mạch khuếch đại/so sánh — xem Giai đoạn 2)
- [ ] 2× ESC (Pump & Starter)
- [ ] 2× Solenoid Valve (Start + Main, xem `CODE_REVIEW_FINDINGS.md`)
- [ ] Glow plug/igniter + driver
- [ ] Micro SD Card (FAT32 format)
- [ ] Nguồn cấp đủ dòng cho starter/pump/glow (xem phần Nguồn & Pin bên dưới)

### Software
- [ ] Arduino IDE 1.8.19+ hoặc 2.x
- [ ] ESP32 Board Support Package
- [ ] Library: **Adafruit MAX31855**
  (không cần ArduinoJson hay ESP32Servo — firmware dùng LEDC PWM trực tiếp
  cho ESC, xem `CLAUDE.md` ở gốc repo)

---

## Cài Đặt Arduino IDE & Upload Firmware

### Bước 1: Cài Arduino IDE
1. Tải từ https://www.arduino.cc/en/software, cài đặt theo hướng dẫn

### Bước 2: Thêm ESP32 Board
1. **File → Preferences** → thêm URL Board Manager:
   `https://dl.espressif.com/dl/package_esp32_index.json`
2. **Tools → Board → Board Manager** → tìm "ESP32" (tác giả Espressif Systems) → cài
3. Chọn board: **ESP32 Dev Module**

### Bước 3: Cài Library
**Sketch → Include Library → Manage Libraries** — tìm và cài:

| Library | Tác giả |
|---|---|
| Adafruit MAX31855 | Adafruit Industries |

> Không cần cài ESP32Servo — ESC (pump/starter) dùng LEDC PWM có sẵn trong
> ESP32 Arduino core. Xem `CLAUDE.md` ở gốc repo.

### Bước 4: Cấu Hình Board & Upload
```
Board:           ESP32 Dev Module
Upload Speed:    115200
Flash Size:      4MB
Port:            COM3 (Windows) hoặc /dev/ttyUSB0 (Linux)
```
Mở `PROJECT_CURRENT/Firmware/ECU_TestV1_EGT_DRY_START_PATCH/ECU_TestV1_EGT_DRY_START_PATCH.ino`
→ Click **Upload** (hoặc Ctrl+U) → chờ "Done uploading" (~30-60s).

**Nếu upload thất bại** ("Failed to connect to ESP32: Timed out"):
1. Giữ nút **Boot** trên board trong lúc upload, thả ra khi thấy "Connecting..."
2. Thử lại, hoặc giảm Upload Speed xuống 9600 để chẩn đoán
3. Kiểm tra driver CH340 đã cài (Windows): http://www.wch.cn/download/ch341ser_exe.zip

### Bước 5: Mở Serial Monitor
**Tools → Serial Monitor** (Ctrl+Shift+M): Baud **115200**, Line ending **Newline**.

Output kỳ vọng ngay sau boot:
```
Test ECU V1 WebUI/TestWizard booted.
MAX31855 begin() = OK (hoặc CHECK_WIRING)
RPM edge = RISING
SD_LOG: OK file=/ECU000.CSV (hoặc FAIL file=...)
Outputs safe. Auto-start disabled. Type help.
```

**Nếu Serial Monitor trống**: kiểm tra baudrate = 115200, upload lại sketch, nhấn nút Reset trên board.

---

## Sơ Đồ Đấu Nối GPIO (Pinout)

```
MAX31855 (EGT):    CLK=18   CS=5    DO=19
RPM sensor:        Signal=33
Pump ESC:          Signal=26 (PWM)
Starter ESC:       Signal=25 (PWM)
Valve 1 (Start):   17 (digital)
Valve 2 (Main):    16 (digital)
Ignition/Glow:     32 (digital)
User Button:       22 (digital, active-LOW, pull-up nội bộ)
Status LED:        2 (onboard, active-LOW)
SD Card (SPI):     CS=13  SCK=14  MOSI=23  MISO=27
```

**Kết nối tối thiểu để test không cần động cơ**: ESP32 + MAX31855 + thermocouple
+ RPM sensor + SD card. Không cần ESC/valve/glow để test qua Web UI cơ bản.

---

## Nguồn & Pin — Lưu Ý Bắt Buộc

- **Không cắm thẳng pin LiPo (2S/3S) vào rail 5V logic của ESP32/mạch RPM sensor**
  — rail này cần nguồn **đã ổn áp qua UBEC 5V** riêng, không phải điện áp pin thô.
- **Starter/Pump ESC**: lấy điện trực tiếp từ pin chính — kiểm tra ESC ghi rõ
  dải điện áp hỗ trợ (ví dụ "2S-4S") trước khi chọn pin.
- **Van solenoid + glow plug**: nếu ghi định mức thấp (ví dụ "DC:6V"), phải
  cấp qua UBEC riêng phù hợp dòng (glow plug thường kéo dòng lớn, 3-8A — cần
  UBEC công suất cao hơn UBEC nhỏ dùng cho ESP32/logic).
- **Chọn dòng xả pin (C-rating)** đủ cho tải đỉnh lúc starter cranking + glow
  + bơm chạy cùng lúc — ước tính và kiểm tra thực tế bằng cách đo sụt áp khi
  `test starter_ign` chạy.
- **Nguồn dòng thấp (ví dụ adapter 12V 2A) KHÔNG đủ chạy starter thật** —
  motor sẽ khựng/giật giật/dừng dù firmware vẫn gửi PWM đều đặn (đây là
  triệu chứng thiếu dòng cấp nguồn, không phải lỗi firmware). Dùng ATX PSU
  hoặc bench PSU chịu dòng ≥15-20A, hoặc pin LiPo phù hợp để test thật.

---

## Giai đoạn 0 — Chuẩn bị trước khi cấp điện

### Checklist chung
- [ ] Kill switch vật lý (NC) đã lắp và test cơ học (không dựa vào firmware)
- [ ] Bình lửa CO2 trong tầm với
- [ ] Bàn test cố định động cơ chắc chắn, không ai đứng ngay trục quay
- [ ] Chưa gắn ống dẫn nhiên liệu vào engine thật (test bench trước)
- [ ] Thẻ SD đã format FAT32, gắn vào ECU
- [ ] Firmware mới nhất đã nạp qua Arduino IDE

### Checklist đấu nối vật lý (kiểm tra bằng mắt/đồng hồ trước khi cấp điện)

| Điểm kiểm tra | Yêu cầu |
|---|---|
| GPIO18/5/19 → MAX31855 CLK/CS/DO | Đúng thứ tự, không ngược |
| Thermocouple | Loại K, không phải J hoặc T |
| GPIO33 → RPM sensor | Qua chuỗi khuếch đại/so sánh (xem Giai đoạn 2), không nối thẳng KMZ10A |
| GPIO26/25 → Pump/Starter ESC | Dây tín hiệu PWM, không phải dây nguồn |
| GPIO17/16 → Valve 1/2 | Qua MOSFET/relay driver, không nối thẳng cuộn solenoid |
| GPIO32 → Ignition/Glow | Qua MOSFET driver phù hợp dòng glow plug |
| GPIO22 → User Button | Pull-up, active LOW |
| SD: CS=13 SCK=14 MOSI=23 MISO=27 | Đúng pinout |
| Nguồn ESP32 | 5V ±0.2V qua UBEC riêng, tách biệt nguồn ESC (xem phần Nguồn & Pin) |
| Không ngắn mạch | Đo điện trở GND-VCC khi CHƯA cấp điện |

---

## Giai đoạn 1 — Kiểm tra tĩnh (không cấp nhiên liệu, không quay starter)

Kết nối Serial Monitor 115200 baud hoặc mở Web UI `192.168.4.1`
(WiFi: **ECU_TestV1**, pass: **admin1234**).

| Bước | Lệnh | Kỳ vọng |
|---|---|---|
| 1.1 | `status` | ECU in ra MODE=WAITING, không lỗi |
| 1.2 | `showcfg` | Xem toàn bộ config mặc định, ghi lại để đối chiếu sau |
| 1.3 | `test egt` | EGT=OK và nhiệt độ phòng (~20-30°C). Nếu FAULT → kiểm tra dây MAX31855 trước khi đi tiếp |
| 1.4 | `test rpm_noise` | RNOISE=CLEAN hoặc NO_SIGNAL (không quay gì cả → NO_SIGNAL là bình thường) |
| 1.5 | `sdstatus` rồi `sdtest` | SD=OK, file ECU0xx.CSV được tạo, event ghi được |

**PASS điều kiện**: cả 5 mục trên không có lỗi. Đây là bước bắt buộc trước
khi chạm vào bất kỳ thứ gì có chuyển động.

**Web UI**: mở dashboard, kiểm tra hiển thị EGT/RPM/Mode=WAITING, Event Log
có dòng boot, Test Wizard tab hiện đủ 9 mục `NOT_RUN`.

---

## Giai đoạn 2 — Hiệu Chỉnh & Xác Nhận Cảm Biến RPM (KMZ10A)

> KMZ10A **không phải Hall sensor thông thường** — đây là cảm biến
> **từ trở anisotropic (AMR)** dạng cầu Wheatstone, output analog vi sai
> mV, cần qua toàn bộ chuỗi khuếch đại + so sánh trước khi thành xung
> digital cho ESP32. Giai đoạn này gồm 2 phần: **A** (oscilloscope DSO152,
> chỉnh phần cứng analog) và **B** (firmware bench, quét toàn dải PWM).

### Sơ Đồ Signal Chain

```
KMZ10A (U17, header 4 chân)
  Pin 1: +V0 → SENSOR_P [TP: U13]   Pin 3: −V0 → SENSOR_N [TP: U12]
  Pin 4: VCC → +5V                   Pin 2: GND → GND
        │ R41/R42 (100Ω) + C19 (1nF lọc vi sai)
        ▼
   INA826 U20 — Gain = 1 + 100k/2.7k ≈ 38×, REF=GND, V+ pin6=VREF(2.5V)
        │ INA_OUT [TP: U3]
        ▼
   C15(10µF) + R35(1M) + R37(4K7) — AC coupling + LPF
        ▼
   LM358 U18 Op-Amp 1 ← RP1 100K (OFFSET)
        ▼
   LM358 U18 Op-Amp 2 ← RP2 100K (GAIN)
        │ LMV358_OUT [TP: U1] (tên net/testpoint trên board, IC thực tế là LM358)
        ▼
   R32(10K) + C2(4.7nF LPF)
        ▼
   LMV393 U19 Comparator (Schmitt, hysteresis R36 470K)
   IN− = VTH_RPM [TP: U21] ← RP3 10K (THRESHOLD)
        │ RPM_OUT [TP: U2] ← ĐIỂM ĐO QUAN TRỌNG NHẤT
        ▼
   J_RPM_OUT1 → cáp ngoài → RPM_PIN_IN1
        │ R10(10K pull-up 3.3V) + R2(1K series) + D1(TVS 3.3V)
        ▼
   GPIO33 (ESP32 NodeMCU-32S)
```

### Bản Đồ Testpoint

| Ký hiệu | Tên | Loại tín hiệu | Dùng cho |
|---|-----|---|---|
| U15 | TP_GND | 0V reference | Kẹp GND probe suốt quá trình đo |
| U16 | TP_5V | DC +5V | Kiểm tra nguồn mạch analog |
| U14 | TP_VREF | DC ~2.5V | Kiểm tra mid-rail |
| U13/U12 | TP_SENSOR_P/N | Analog mV | Output cầu KMZ10A |
| U3 | TP_INA_OUT | Analog ×38 | Output INA826 |
| U1 | TP_LMV358_OUT | Analog trimmed | Trước comparator |
| U21 | TP_VTH_RPM | DC 0–5V | Ngưỡng comparator (chỉnh RP3) |
| U2 | **TP_RPM_OUT** | **Digital 0/5V** | **Xung RPM cuối — quan trọng nhất** |
| GPIO33 | Trực tiếp | Digital 0/3.3V | Vào ESP32 |

### 3 Trimpot

| Trimpot | Giá trị | Chức năng | Nếu chỉnh sai |
|---|---|---|---|
| **RP1** | 100K | OFFSET — dịch tâm DC của sóng, không đổi biên độ | Lệch tâm khỏi 2.5V → mất xung ở 1 trong 2 cực nam châm, RPM đọc chỉ bằng nửa thật |
| **RP2** | 100K | GAIN — kéo giãn/co biên độ AC, không đổi tâm DC | Quá thấp → không đủ vượt ngưỡng (NO_SIGNAL); quá cao → clipping, double-pulse, RPM giả cao |
| **RP3** | 10K | THRESHOLD — dịch ngưỡng so sánh VTH_RPM của comparator | Quá thấp → double-pulse/xung rác; quá cao → mất xung hoàn toàn |

> Xem giải thích chi tiết + sơ đồ dạng sóng cho từng trimpot ở phần
> **A3/A4/A5** bên dưới.

### Cài Đặt DSO152

> DSO152 chỉ có 3 chế độ trigger: **Auto** (tự động quét liên tục, hiển thị
> cả khi chưa đủ điều kiện trigger — dùng cho hầu hết các bước quan sát
> tín hiệu lặp lại/DC), **Normal** (chỉ vẽ lại màn hình khi tín hiệu thật
> sự cắt qua mức trigger — dùng khi muốn khóa hình ổn định hơn cho xung
> lặp đều), **Single** (bắt 1 lần rồi dừng — ít dùng trong quy trình này).
> Không có tùy chọn chọn cạnh lên/xuống (rising/falling) riêng.

| Bước | Probe tại | Coupling | Volt/div | Time/div | Mode |
|---|---|---|---|---|---|
| A1a | TP_5V (U16) | DC | 2V | 10ms | Auto |
| A1b | TP_VREF (U14) | DC | 1V | 10ms | Auto |
| A2 | TP_INA_OUT (U3) | AC | 500mV | 2ms | Auto |
| A3/A4 | TP_LMV358_OUT (U1) | DC | 1V | 2ms | Auto |
| A5 | TP_RPM_OUT (U2) | DC | 2V | 2ms | Auto (hoặc Normal nếu muốn khóa hình ổn định hơn) |
| A-cuối | GPIO33 | DC | 2V | 2ms | Auto |

> GND probe **luôn cắm vào U15 (TP_GND)**.

> **Time/div theo tốc độ quay**: các giá trị Time/div ở trên (2ms) hợp khi
> rotor quay **nhanh** (quạt/khí nén mạnh, hoặc starter ở A5). Nếu **quay tay
> chậm ~1–3 vòng/giây**, một chu kỳ kéo dài ~200–500ms nên 2ms/div sẽ không
> thấy hết sóng — hãy **nới Time/div lên ~50–100ms/div** để thấy trọn 1–2 chu
> kỳ trước, rồi thu lại khi cần xem chi tiết đỉnh sóng. Volt/div và điểm nối
> probe giữ nguyên như bảng.

### GIAI ĐOẠN A — Hiệu Chỉnh Analog Bằng Oscilloscope

> **Quy ước nối DSO152 (áp dụng cho mọi bước A1–A5):**
> - **Que mát** (kẹp cá sấu, đầu ⏚) → luôn cắm cố định vào **U15 (TP_GND)**,
>   không tháo ra suốt Giai đoạn A.
> - **Que tín hiệu** (đầu nhọn) → chạm vào testpoint của từng bước; mỗi bước
>   dưới đây có dòng **🔌 Nối probe** ghi rõ testpoint và vị trí trên mạch.
> - DSO152 chỉ có **1 kênh** → chỉ đo 1 điểm mỗi lần; di chuyển que tín hiệu
>   lần lượt qua các testpoint theo thứ tự A1 → A2 → A3 → A4 → A5.

> **Bố trí sensor–magnet trên bản dựng này (đọc kỹ trước bước A2):**
> nam châm neodymium gắn **cố định** trong bánh nén/turbine bằng **nhôm**,
> cách mặt KMZ10A khoảng **~5cm** — khoảng cách do kết cấu cơ khí quyết định,
> **không chỉnh được** khi test. Nhôm không chắn từ trường nên tại ~5cm vẫn
> thu đủ biên độ (đã kiểm chứng thực tế trên bản dựng này). Do đó khi tín hiệu
> yếu/không có, **đừng đi tìm cách "đưa magnet lại gần"** — hãy soát **hướng
> đặt KMZ10A**, từ tính nam châm, và dây/nguồn.

**Cách quay magnet khi rotor nằm bên trong (không quay tay được)**

Magnet gắn trên spinner nut/compressor wheel thường nằm sâu trong cửa hút,
không phải lúc nào cũng thò tay quay trực tiếp được. Dùng phương pháp khác
nhau tùy mục đích từng bước:

- **Các bước A2-A4 (cần quan sát tín hiệu "sạch", không nhiễu điện)**:
  dùng **quạt hoặc khí nén thổi vào cửa hút** để cánh quạt/compressor wheel
  tự do quay theo luồng khí. Đây là cách quay **không sinh nhiễu điện**
  (hoàn toàn thụ động, không motor/ESC nào chạy), phù hợp nhất để chỉnh
  trimpot chính xác. Tốc độ không cần chính xác — chỉ cần quay đều vài
  giây để quan sát dạng sóng ổn định.
- **Bước A5, phần test EMI (cố ý đưa nhiễu thật vào)**: dùng **starter
  motor** qua `starttest <us> <ms>` hoặc Test Wizard — mục đích ở đây khác
  hẳn: cần nguồn nhiễu ESC/motor thật để kiểm tra RP3 đã chỉnh có đủ margin
  chống nhiễu hay không.
- Nếu rotor vẫn thò tay quay được (một số turbine cửa hút đủ rộng) — quay
  tay là cách đơn giản nhất, vẫn dùng bình thường cho mọi bước A2-A5.

**A1 — Kiểm tra nguồn** (không cần quay magnet)

> 🔌 **Nối probe**: que mát → **U15 (TP_GND)**. Que tín hiệu: bước **A1a**
> chạm **U16 (TP_5V)** — testpoint rail +5V; bước **A1b** chuyển sang
> **U14 (TP_VREF)** — testpoint mid-rail 2.5V.

- U16: DC phẳng +5.0V ±0.2V. U14: DC ổn định 2.4-2.6V.
- Sai → kiểm tra BEC/hàn R40/R39/C23/C1 trước khi tiếp tục.

**A2 — Xem tín hiệu INA826 (U3)**

> 🔌 **Nối probe**: que tín hiệu → **U3 (TP_INA_OUT)** — testpoint ngay sau
> IC khuếch đại đo lường **INA826 (U20)**; que mát → **U15 (TP_GND)**. AC coupling.

- Quay magnet ~1-3 vòng/giây (quạt/khí nén hoặc tay, xem trên), AC coupling.
- Kỳ vọng: sóng sin/quasi-sin, biên độ 200mV-1Vpp.
- Không thấy gì → khoảng cách magnet cố định (~5cm, xem ghi chú đầu Giai đoạn A)
  **không phải chỗ để chỉnh**: kiểm tra **hướng đặt KMZ10A** (xoay 90° thử),
  xác nhận nam châm còn từ tính, soát lại dây/nguồn (A1).

*Nếu sóng không ra hình sin/quasi-sin*:

| Dạng sóng thấy được | Nguyên nhân khả dĩ | Xử lý |
|---|---|---|
| Đỉnh bị cắt phẳng (clipping/vuông hóa) ngay tại U3 | INA826 bão hòa do nam châm quá mạnh (gain ×38 cố định) — hiếm gặp ở ~5cm | Khoảng cách cố định không đổi được → nếu thật sự clipping tại U3 thì thay nam châm yếu hơn. Nếu U3 vẫn tròn mà chỉ méo ở U1 → đó là clipping tầng sau, giảm RP2 (A4) |
| Răng cưa/tam giác thay vì sin | Quay không đều (quạt thổi giật cục, hoặc tay quay không đều) | Quay đều hơn — không phải lỗi mạch |
| Nhiễu loạn, không thấy chu kỳ rõ | EMI/nhiễu nền, dây tín hiệu gần dây công suất, tiếp xúc lỏng | Kiểm tra dây, tách xa nguồn nhiễu, xem lại A1 |
| "Nhọn"/không tròn nhưng vẫn đều theo chu kỳ | Bình thường với AMR sensor — đây là lý do gọi "quasi-sin" | Không cần sửa, miễn biên độ đạt 200mV-1Vpp và có chu kỳ rõ |
| Hoàn toàn phẳng, không AC | Sensor chết/sai hướng/mất nguồn | Xem lại A1, kiểm tra hướng đặt KMZ10A, xác nhận nam châm còn từ tính |

Nguyên tắc chung: miễn sóng **có chu kỳ rõ ràng, biên độ đủ, lặp lại đều
theo tốc độ quay** thì không bắt buộc phải là sin hoàn hảo — bước RP1/RP2/
RP3 tiếp theo sẽ xử lý phần còn lại.

**A3 — Chỉnh RP1 (Offset) tại U1**

> 🔌 **Nối probe**: que tín hiệu → **U1 (TP_LMV358_OUT)** — testpoint sau
> 2 tầng op-amp **LM358 (U18)**, ngay trước comparator; que mát →
> **U15 (TP_GND)**. DC coupling.

*RP1 chỉnh gì*: RP1 là trimpot hồi tiếp của tầng LM358 Op-Amp 1 — nó
**dịch mức DC (offset)** của tín hiệu analog lên/xuống, không ảnh hưởng
biên độ AC. Vặn RP1 tương đương "kéo" cả sóng lên hoặc xuống theo trục
điện áp, giữ nguyên hình dạng sóng.

*Vì sao quan trọng*: Comparator (LMV393, bước A5) so sánh tín hiệu này với
ngưỡng VTH_RPM cố định quanh 2.5V. Nếu sóng bị lệch tâm (không đối xứng
quanh 2.5V), comparator sẽ kích **không đều giữa 2 cực nam châm** (N và S)
— ví dụ cực N tạo xung tốt nhưng cực S không đủ vượt ngưỡng → **mất một
nửa số xung mỗi vòng quay**, RPM đọc được chỉ bằng nửa thực tế.

*Thao tác*: DC coupling tại U1, quay magnet đều ~2 vòng/giây, vặn RP1 cho
đỉnh dương và đỉnh âm của sóng **cách đều 2.5V**.

```
RP1 lệch (offset sai):              RP1 đúng (đã chỉnh):
    4.0V ┐ đỉnh dương                   3.5V ┐ đỉnh dương
         │  (cách 2.5V: 1.5V)                │  (cách 2.5V: 1.0V)
    2.5V ─┼─── VREF                     2.5V ─┼─── VREF (đúng tâm)
         │                                     │
    2.0V ┘ đáy                            1.5V ┘ đáy
         (cách 2.5V: 0.5V — LỆCH!)             (cách 2.5V: 1.0V — CÂN)
```

*Kiểm tra*: ghi điện áp đỉnh+ và đỉnh−, tính hiệu với 2.5V — hai số này
phải **bằng nhau** (sai lệch ≤0.1V là chấp nhận được).

**A4 — Chỉnh RP2 (Gain) tại U1**

> 🔌 **Nối probe**: **giữ nguyên** que tín hiệu ở **U1 (TP_LMV358_OUT)** như
> A3 (que mát vẫn ở U15) — A4 đo cùng điểm với A3, chỉ khác trimpot cần vặn.

*RP2 chỉnh gì*: RP2 là trimpot hồi tiếp của tầng LM358 Op-Amp 2 — nó
**thay đổi hệ số khuếch đại (gain)** của tín hiệu, tức là kéo giãn/co lại
biên độ dao động AC, không dịch tâm DC (tâm vẫn giữ ở 2.5V nhờ RP1 đã
chỉnh ở A3).

*Vì sao quan trọng*: Biên độ càng lớn thì tín hiệu càng dễ vượt qua ngưỡng
comparator (bước A5) một cách dứt khoát, có margin chống nhiễu tốt. Nhưng
nếu khuếch đại quá mức, đỉnh sóng sẽ bị **cắt phẳng (clipping)** do vượt
quá dải điện áp ra của op-amp — sóng vuông hóa một phần thay vì sin trơn,
gây ra **double-pulse** (comparator kích 2 lần trên 1 đỉnh bị méo) hoặc
đọc RPM cao giả (OVERSPEED oan).

*Thao tác*: vẫn probe tại U1, quay magnet đều, vặn RP2 để đạt biên độ
**1–2Vpp**:

```
RP2 quá thấp (<0.5Vpp):       RP2 tối ưu (1-2Vpp):        RP2 quá cao (clipping):
   2.7V ┐ đỉnh thấp              3.5V ┐ đỉnh tròn              4.5V ┌──┐ đỉnh PHẲNG
        │ không đủ vượt               │                              │  │ (op-amp bão hòa)
   2.5V ─┼─                     2.5V ─┼───                     2.5V ─┼───
        │ ngưỡng comparator           │                              │  │
   2.3V ┘ → KHÔNG ra xung        1.5V ┘ đáy tròn               0.5V └──┘ đáy PHẲNG
   (NO_SIGNAL dù đang quay)      (kích comparator rõ ràng)     (double-pulse, RPM giả cao)
```

*Nhận biết clipping*: đỉnh/đáy sóng "phẳng" thay vì bo tròn tự nhiên →
**giảm RP2**. Nếu biên độ vẫn dưới 0.5Vpp dù đã vặn RP2 tối đa → kiểm tra
lại A2 (biên độ INA_OUT quá nhỏ, thường do nam châm yếu hoặc lệch hướng
sensor — không phải do khoảng cách vì khoảng cách cố định) trước khi tiếp
tục chỉnh RP2.

> ⚠️ **Trần output thực tế của LM358 KHÔNG gần 5V**: IC lắp trên board là
> **LM358** (không phải LMV358 rail-to-rail như tên net `TP_LMV358_OUT` dễ
> gây nhầm — xem ghi chú ở đầu tài liệu). Tầng ra LM358 là kiểu cũ
> (class-AB), **không kéo lên sát V+** được — với VCC≈5V, mức cao thực tế
> chỉ đạt khoảng **3.1–3.8V** dù RP2 đã vặn hết cỡ. Đây là **giới hạn vật lý
> của chip**, không phải dấu hiệu chỉnh RP2 sai. Nếu đỉnh sóng dừng ở
> ~3.1–3.8V nhưng vẫn **bo tròn tự nhiên** (không phẳng cứng) và comparator
> (bước A5) vẫn ra xung sạch → **không cần cố vặn RP2 để kéo cao hơn**, vô
> ích và chỉ tăng nguy cơ clipping/double-pulse. Ví dụ "4.5V" trong sơ đồ
> trên chỉ minh họa khái niệm clipping nói chung, không phải mức điện áp
> literal đo được trên board này.

**A5 — Chỉnh RP3 (Threshold) tại U2, xác nhận xung RPM_OUT**

> 🔌 **Nối probe**: que tín hiệu → **U2 (TP_RPM_OUT)** — testpoint xung ra
> của comparator **LMV393 (U19)**, đây là **điểm đo quan trọng nhất**; que
> mát → **U15 (TP_GND)**. DC coupling, 2V/div. (Khi cần đọc ngưỡng bằng số
> ở cuối bước, chuyển tạm que tín hiệu sang **U21 / TP_VTH_RPM**.)

*RP3 chỉnh gì*: RP3 đặt điện áp **VTH_RPM** — ngưỡng so sánh (IN− của
LMV393 comparator). Đây là "lằn ranh" điện áp: sóng analog vượt lên trên
VTH_RPM → RPM_OUT chuyển mức cao; xuống dưới → chuyển mức thấp. RP3 không
ảnh hưởng dạng sóng analog (đó là việc của RP1/RP2) — nó chỉ quyết định
**tại điểm nào trên sóng thì được tính là 1 xung**.

*Vì sao quan trọng*: Đây là bước quyết định trực tiếp chất lượng xung
digital cuối cùng vào GPIO33 — mọi sai số ở RP1/RP2 trước đó cuối cùng
đều thể hiện ra ở đây. R36 (470K) tạo **hysteresis** (độ trễ ngưỡng) cho
comparator — nghĩa là ngưỡng bật và ngưỡng tắt lệch nhau một chút, giúp
chống nhiễu quanh điểm ngưỡng. RP3 dịch chuyển cả cặp ngưỡng bật/tắt này
lên xuống.

*Thao tác*: probe tại U2 (TP_RPM_OUT), DC coupling, 2V/div, mode Auto
(hoặc Normal nếu muốn khóa hình ổn định hơn), quay magnet đều ~2 vòng/giây.

```
RP3 quá THẤP (ngưỡng dưới VREF quá xa):
  ┌──┐  ┌─┐┌┐  ← double-pulse/xung rác: sóng dao động nhỏ quanh
  │  │  │ ││ │     ngưỡng thấp cũng đủ cắt qua nhiều lần
                → TĂNG RP3 (vặn theo chiều kim đồng hồ)

RP3 ĐÚNG (1 xung sạch/vòng):
  ┌──┐     ┌──┐
  │  │     │  │  ← đẹp, đều, cách đều nhau — đúng 1 xung mỗi cực nam châm
  ┘  └─────┘  └──

RP3 quá CAO (ngưỡng vượt quá đỉnh sóng thật):
  (không thấy xung nào dù magnet đang quay — sóng analog không bao giờ
   chạm tới ngưỡng)
       → GIẢM RP3 (vặn ngược chiều kim đồng hồ)
```

*Cách tìm điểm làm việc tối ưu (margin)*:
1. Từ trạng thái đang có xung sạch, tiếp tục **tăng RP3** từ từ cho đến
   khi xung **vừa biến mất hoàn toàn** → đây là biên trên
2. **Lùi lại 1/4 vòng** (giảm RP3) từ biên trên đó → đây là điểm làm việc
3. Margin 1/4 vòng này là vùng đệm bảo vệ khỏi **trôi ngưỡng do nhiệt độ**
   (linh kiện analog thay đổi nhẹ theo nhiệt độ động cơ) và dao động nguồn
   5V — nếu chỉnh sát biên, chỉ cần trôi nhẹ là mất tín hiệu giữa lúc đang
   chạy động cơ thật

*Test nhiễu EMI*: vẫn probe tại U2, bật starter ESC ở mức thấp (~20%),
quan sát RPM_OUT có xuất hiện spike lạ không (do EMI từ ESC/dây công suất
lan sang dây RPM). Có spike → tăng RP3 thêm ~1/8 vòng, hoặc tăng
`rpmfilter` trong firmware (xem Giai đoạn 2B).

*Đọc VTH_RPM bằng số*: chuyển probe tạm sang U21 (TP_VTH_RPM), ghi lại
điện áp ngưỡng tại điểm làm việc tối ưu — con số này dùng để đối chiếu
nếu sau này nghi ngờ trimpot bị trôi/lệch.

**A-cuối — Xác nhận GPIO33**: cắm J_RPM_OUT1→RPM_PIN_IN1.

> 🔌 **Nối probe**: que tín hiệu → chân **GPIO33** trên ESP32 (hoặc đầu
> **RPM_PIN_IN1** trên board ECU, sau R2/D1); que mát → **U15 (TP_GND)**
> hoặc chân **GND của ESP32** (đã chung mát với mạch RPM). DC coupling, 2V/div.

Kỳ vọng xung **0-3.3V** (D1 TVS clamp giữ không vượt 3.3V). Nếu vẫn thấy 5V
→ D1 lỗi, thay ngay trước khi cấp nguồn ESP32.

### GIAI ĐOẠN B — Quét Toàn Dải PWM Bằng Firmware TEST_STARTER

Dùng `TEST/TEST_STARTER/TEST_STARTER.ino` (firmware bench riêng, không
cần ARM, không bảo vệ) để quét **toàn dải PWM starter thật**, thay vì chỉ
quan sát bằng tay quay chậm trên oscilloscope.

**Đấu nối**: Starter ESC signal → GPIO25, RPM sensor → GPIO33 (giống mạch chính).

**⚠️ An toàn**: THÁO cánh/impeller khỏi starter trước khi test. Nguồn ESC
tách riêng nguồn ESP32, đủ dòng (xem phần Nguồn & Pin).

**Upload**: mở `TEST/TEST_STARTER/TEST_STARTER.ino`, board ESP32 Dev Module,
không cần lib ngoài (LEDC PWM có sẵn trong core).

**Test qua Serial HOẶC qua Web** (không bắt buộc phải dùng Serial Monitor):
- Serial: 115200 baud, Newline
- Web: SoftAP **TEST_STARTER** / pass **test1234** → `http://192.168.4.1` —
  cùng bộ lệnh qua nút bấm/ô nhập, tiện khi test bằng điện thoại

**Bảng lệnh**:

| Lệnh | Chức năng |
|---|---|
| `+` / `-` | Tăng/giảm PWM starter 1 bước (mặc định 10µs) |
| `0` hoặc `s` | Dừng starter (PWM về 1000µs) |
| `step <us>` | Đổi bước tăng/giảm (1..200) |
| `pwm <us>` | Đặt PWM trực tiếp (1000..2000) |
| `ppr <n>` | Số xung/vòng (1=nam châm, 2=quang học) |
| `filter <us>` | Bộ lọc glitch RPM (20..2000), mặc định 120 |
| `edge rising\|falling` | Cạnh kích RPM |
| `reset` | Xóa bộ đếm & lịch sử RPM |
| `status` / `help` | In trạng thái / menu lệnh |

> Firmware ECU chính có mục **"Starter Manual Test"** trên Web UI dashboard
> cho phép chạy `starttest <us> <ms>` trực tiếp từ trình duyệt (không cần
> arm2) — không bắt buộc phải dùng Serial.

**Đọc dòng trạng thái** (in 2 lần/giây):
```
PWM=1200us | RPM=8450 (win 8410) | raw=141 acc=141 rej=0 (0.0%) | jit=4.2% cv=1.1% | NOISE=CLEAN STAB=STABLE
```

| Trường | Ý nghĩa |
|---|---|
| `PWM` | Mức PWM hiện tại. `(OFF)` khi =1000µs |
| `RPM` / `win` | RPM tức thời / trung bình cửa sổ 100ms |
| `raw`/`acc`/`rej` | Cạnh thô / chấp nhận / bị lọc |
| `jit` | Jitter chu kỳ (max-min)/avg |
| `cv` | Hệ số biến thiên RPM (stddev/mean) |
| `NOISE`/`STAB` | Đánh giá nhiễu / độ ổn định tự động |

**Ngưỡng NOISE**: `CLEAN` (reject≤5%, jit≤15%) · `WARN` (reject>5% hoặc jit>15%)
· `NOISY` (reject>20% hoặc jit>40%) · `NO_SIGNAL` (không cạnh nào).

**Ngưỡng STAB** (sau khi PWM ổn định 1.5s): `STABLE` (CV≤2%) · `WARN` (2-5%)
· `UNSTABLE` (>5%) · `SETTLING` (mới đổi PWM) · `OFF` (PWM=1000µs).

**Quy trình quét**:
1. Test tĩnh (PWM=OFF) 30s: kỳ vọng `raw≈0`, `NOISE=NO_SIGNAL`. Có `acc>0` → nhiễu nền, quay lại A5.
2. Rà quét `+` từng bước nhỏ (vd +10µs từ 1100µs), chờ `STAB` khỏi `SETTLING` rồi ghi `NOISE`/`STAB`.
3. Ghi bảng PWM→RPM→NOISE→STAB (mẫu bên dưới).
4. `NOISY` ở PWM cao → tăng `filter 300`, thêm tụ 100nF tại GPIO33, tách dây RPM xa dây ESC. Vẫn không hết → quay lại A5 tăng margin RP3.
5. **GO/NO-GO**: toàn dải phải đạt `NOISE=CLEAN` và `STAB=STABLE` trước khi chuyển sang firmware ECU chính.

**Bảng ghi kết quả quét** (điền khi test):

| PWM (µs) | RPM | raw | acc | rej% | jit% | cv% | NOISE | STAB |
|---|-----|-----|-----|---|---|-----|---|---|
| 1000 (OFF) | | | | | | | | |
| 1100 | | | | | | | | |
| 1150 | | | | | | | | |
| 1200 | | | | | | | | |
| 1250 | | | | | | | | |

**Xác nhận cuối** (trên firmware ECU chính, không phải TEST_STARTER):
```
rpmdetail on
```
Quay tay đều ~1 vòng/giây → Serial phải hiện RPM ≈ 60 (ppr=1), `NOISE=CLEAN`,
`rej%` < 5%.

---

## Giai đoạn 3 — Test từng bộ phận (Test Wizard, KHÔNG nhiên liệu)

Các lệnh test **không cần `arm2`** (đã bỏ yêu cầu ARM cho phần test, chỉ còn
yêu cầu ở `startidle`/`autostart on`/tắt interlock — xem Giai đoạn 5).

```
test ign          -> glow plug bật 1s, quan sát dòng điện/nhiệt bằng tay (cẩn thận nóng)
test starter      -> starter quay 5s ở us cấu hình, xem RPM có tăng lên không
                     (RPM/RNOISE được chốt LÚC starter còn quay, ngay trước khi tắt —
                      tránh rest-guard ép RPM=0; 5s đủ để tốc độ ổn định, hết báo NOISY)
test starter_ign  -> starter + glow cùng lúc, kiểm tra EMI có làm nhiễu RPM không (resetRpmStats() trước bước này đã fix trong CODE_REVIEW_FINDINGS.md)
test valve1        -> Valve 1 = Start solenoid valve
test valve2        -> Valve 2 = Main oil valve
```

Với mỗi test, dùng `checklist` để xem kết quả — tất cả phải chuyển từ
`NOT_RUN` → `PASS`. Nếu `FAIL` — sửa phần cứng trước khi tiếp tục (đừng
chỉnh firmware để né test).

> **Chặn khi EGT còn nóng**: `test ign`/`test starter_ign`/`test valve1`/`test valve2`
> đều bị chặn nếu EGT còn nóng hơn `cooldownTargetC` (giống hệt lệnh trực tiếp
> `ignpulse`/`valve on`) — tránh châm lửa/mở van vào lõi còn nóng sau abort.
> Riêng `test starter` (chỉ starter) vẫn cho chạy vì giúp làm mát. Nếu test bị
> `BLOCKED` do nóng, đợi nguội hoặc chạy tiếp cooldown trước khi test lại.

**Component test khác (tùy chọn, bench-only, không cần arm2)**:
```
starttest <us> <ms>   -> vd: starttest 1200 3000
ignpulse <ms>          -> vd: ignpulse 1500
valve1 on/off | valve2 on/off
```

> ⚠️ **`valve1 on`/`valve2 on` KHÔNG còn tự tắt sau 10s** — van sẽ mở cho tới
> khi bạn gõ `valve1 off`/`valve2 off` (hoặc bấm nút OFF trên Web UI). Luôn
> nhớ tắt van sau khi test xong, đặc biệt khi có nhiên liệu thật.

---

## Giai đoạn 4 — Test bơm nhiên liệu riêng (KHÔNG gắn ống vào engine)

⚠️ Tháo ống dẫn nhiên liệu ra khỏi engine, xả vào cốc hứng riêng.

```
pumptest 1160 1500   -> bơm chạy 1500ms ở 1160us, đo ml thực tế đối chiếu bảng calib
```

> Trần bench `pumptest` hiện là **1000..1225µs** (thời lượng `ms` **không giới hạn**
> — nhập bao nhiêu chạy bấy nhiêu, tự tắt sau `ms`; `starttest` cũng vậy). Nút "Pump prime" trên Web UI
> chạy ở `pumpTestUs` = **1160µs** (mặc định) — mức flow **thấp nhất đã đo thực
> tế** (50 ml/phút), an toàn hơn cho bench test. Vẫn nên quét vài mức us khác
> để xác nhận độ tuyến tính (dùng panel **"Pump Manual Test"** trên Web UI,
> hoặc lệnh `pumptest <us> <ms>` trực tiếp qua Serial).
>
> **Các mức PWM này chỉnh trực tiếp được** (không hard-code): qua Serial
> `set intro/idleus/maxus/pumptestus <us>` và `set purgeus/spinus/assistus <us>`,
> hoặc qua panel **"Starter & Fuel PWM"** trên Web UI (tự nạp giá trị từ config).
> Lưu ý: các lệnh tune PWM/limit chỉ nhận khi ở **WAITING/ABORTED**, không nhận
> khi đang chạy.

**Bảng hiệu chuẩn pump** (đo thực tế, khớp firmware):

| ESC (µs) | Lưu lượng (ml/phút) |
|---|---|
| 1000 | 0 (tắt) |
| 1160 | 50 (tối thiểu) |
| 1175 | 80 |
| 1250 | 265 |
| 1260 | 280 |
| 1265 | 360 |
| 1270 | 560 |
| 1300 | 600 (tối đa) |

Lặp lại 2-3 mức us khác nhau để xác nhận độ tuyến tính. Đây là bước cuối
để pass `TEST_PUMP` trong checklist:
```
test pump
```

Sau khi xong, `confirmkill` để xác nhận kill-switch vật lý đã test cơ học:
```
confirmkill
```

**Kiểm tra checklist tổng**:
```
checklist
```
→ `STARTIDLE_CHECK=PASS: OK` (không phải OK_DRY_START_EGT_BYPASS, vì đó là
chế độ né checklist khi cảm biến EGT hỏng — chỉ dùng khi cố ý test khô).

---

## Giai đoạn 5 — Dry-start (quay engine thật, KHÔNG nhiên liệu/lửa)

Mục đích: xác nhận starter đủ mạnh quay trục thật + RPM sensor đọc đúng khi
lắp lên engine, trước khi cho nổ.

Cách kích hoạt dry-start: rút giắc/để hở mạch cảm biến EGT tạm thời (hoặc
dùng `set egtstart dry` để cho phép), lúc đó `startidle` sẽ tự động thành
dry-run (không nhiên liệu/van/mồi lửa vì `dryStartActive=true`). **Không có
lệnh `drystart` riêng** — đây là hành vi tự động của `startidle` khi EGT lỗi.

```
set egtstart dry
arm2
autostart on
arm2
startidle
```

Quan sát: starter quay đúng `dryStartRunMs`, RPM tăng theo, không có mùi
nhiên liệu, không có tia lửa. Dùng `rpmdetail on` để xem RPM có track đúng
tốc độ quay thật không.

Xong bước này, trả cảm biến EGT về đúng dây và:
```
set egtstart strict
```
để khóa lại — từ giờ mọi lần EGT lỗi sẽ chặn start thay vì lặng lẽ dry-run.

**Dừng dry-start**: `stop` (soft stop, vào cooldown) hoặc nhấn button vật lý.

---

## Giai đoạn 6 — Wet-start (khởi động thật, có nhiên liệu + lửa)

**Chỉ làm khi**: Giai đoạn 0-5 đều PASS, EGT gắn đúng và đọc chính xác,
engine cố định chắc chắn, có người đứng cạnh kill switch, có bình chữa cháy.

```
arm2
autostart on
arm2
startidle
```

Firmware tự chạy chuỗi:
`PURGE → SPINUP_PREHEAT → INTRO_FUEL → LIGHTOFF → ACCEL_TO_IDLE → IDLING`

- **PURGE**: starter giữ **ESC_SAFE (1000µs, thật sự 0)** trong `escarmholdms`
  (**2s**) đầu để ESC arm xong trước khi nhận xung khác 0 (tránh "quay vài vòng rồi
  khựng" do ESC mới arm được một phần), rồi giữ nguyên `rampfromus` (1150µs) trong
  `purgestablems` (**10s**) cho ổn định, sau đó mới ramp **+1µs mỗi `rampstepms`
  (250ms ≈ 4µs/s)**, tới khi **RPM > `ignarmrpm` (3000)** thì giữ `purgeTimeMs` (3s)
  thổi sạch. Quá `spinuptimeoutms` (57s, đã cộng sẵn 2s arm-hold + 10s ổn định) không
  đạt RPM → abort `NO_RPM`. Áp dụng cho cả dry test lẫn chạy thật (dùng chung hàm ramp).
- **SPINUP_PREHEAT**: **glow ON `preheatMs` (2s)**, sau đó giữ glow bật.
- **INTRO_FUEL**: bơm nhiên liệu min (`introus` = 1015µs) + mở **Start Valve (Valve 1)**.
- **LIGHTOFF**: chờ `fueldelayms` (1s); xác nhận bắt lửa THẬT khi **EGT ≥ 100°C VÀ dEGT/dt ≥
  `lightoffrise` (15°C/s) giữ `lightoffconfirmms` (0.7s)** → mở **Main Valve (Valve 2)**, chờ
  `postIgnitionHeatMs` (2s), đóng Start Valve, chờ `flameprovems` (2s) xác nhận không mất lửa →
  tắt glow, thành công. Quá `noIgnitionTimeoutMs` (6s) hoặc mất lửa → thất bại (blow-out `purgeoutms` rồi cooldown).
- **ACCEL_TO_IDLE**: nếu lửa còn cháy mà RPM không tăng thì bơm +`accelstepus` mỗi `accelholdms`,
  tới `idleRpm` (42000). Starter trợ lực bám RPM (`assistus`→`ramptous`=1450µs) tới `startermaxrpm`
  (10000) rồi nhả.
- **Mất lửa**: EGT tụt > `flameoutdropc` (10°C) trong 2s **hoặc** < 100°C.

> Toàn bộ mốc trên chỉnh được trong **Web UI → Settings → "Tune — Start sequence"** và lưu vào SD.
> Xem chi tiết trong `QUY_TRINH_KHOI_DONG.md`.

### Bảo vệ động cơ / starter (chạy mọi lúc, mọi mode)

Hai cơ cấu bảo vệ chạy mỗi vòng lặp, đè lên lệnh starter của từng giai đoạn:

1. **Chống khí nóng lan lên đầu máy (soak-back)**: khi **EGT > `cooldownTargetC` (90°C)**
   mà **RPM < `hotSpinMinRpm` (3000)** → starter tự chạy, **bắt đầu ở `hotSpinUs` (1200µs,
   KHÔNG phải 1150µs như ramp lúc khởi động)** rồi **tăng dần +1µs mỗi 0.1s** cho tới khi
   RPM vượt 3000 (giới hạn trần ở `ramptous` = 1450µs). Ramp nhẹ từ 1200 tránh làm cánh
   quạt giảm tốc đột ngột khi guard vào cuộc; khi RPM đã đạt thì **giữ nguyên** mức xung
   (không tăng tiếp, không thả). Dùng cho trường hợp động cơ đang nóng mà dừng/tụt tua —
   giữ luồng khí đúng chiều, tránh khí nóng dội ngược làm hỏng đầu/ổ trước. Khi **EGT < 90°C**
   starter được phép dừng (cooldown cũng kết thúc ở mốc này) và ramp hot-spin reset về 1200µs.
2. **Chống quá tải starter**: khi **RPM > `starterMaxRpm` (15000)** → starter bị **tắt**
   (nhả khỏi cánh quạt) để rotor đã lên tua không kéo quá tải/quá tốc motor đề.

Chỉnh trong **Web UI → Settings → "Bảo vệ động cơ / starter"** (hoặc `set startermaxrpm`,
`set hotspinminrpm`, `set hotspinus`, `set cooltarget`), lưu vào SD như các tham số khác.

Theo dõi bằng Web UI (gauge RPM/EGT + chip STAGE) hoặc `status`:
- `STAGE=` chuyển đúng thứ tự trên
- `EGT=` tăng qua 100°C khi bắt lửa
- `RPM=` tăng dần đến gần idleRpm

Nếu bất kỳ đâu bị **ABORT** (OVER_TEMP, NO_IGNITION, NO_RPM_RISE,
RPM_SIGNAL_LOST, OVERSPEED, COMM_TIMEOUT...) — **đọc kỹ lý do trên Serial
trước khi `clearabort`**. Không type `clearabort` theo phản xạ.

### ⚠️ Xả nhiên liệu tồn dư trước khi thử start lại (sau NO_IGNITION / ACCEL_TO_IDLE_TIMEOUT)

Theo manual EnJet E80/E100 (`REFERENCES/Documentation/Engine_Manual_E80_E100.pdf`):
nếu lần start trước bị fail (đặc biệt `NO_IGNITION` — đã phun dầu nhưng
không bắt lửa), nhiên liệu chưa cháy **vẫn còn đọng lại trong buồng đốt**.
Cố start lại ngay có thể gây cháy lớn khi lượng dầu tồn dư này bắt lửa
đột ngột cùng lúc với lần mồi mới.

**Quy trình xả trước khi start lại**:
1. Nghiêng động cơ, **đuôi (exhaust) hướng xuống dưới**
2. Dùng `starttest <us> <ms>` (hoặc quay tay nếu có thể) để quay rotor vài
   giây, không phun thêm nhiên liệu — mục đích thổi bay dầu tồn đọng ra
   khỏi buồng đốt qua đuôi
3. Sau đó mới `clearabort` và thử `startidle` lại

Bỏ qua bước này nếu lần fail là do abort SỚM (`NO_STARTER_RPM`,
`OVER_TEMP` trước khi có nhiên liệu) — chỉ áp dụng khi đã ở stage
`ST_INTRO_FUEL` trở lên (đã phun dầu) mà chưa đánh lửa thành công.

Khi vào `MODE_IDLING` ổn định vài chục giây, không dao động RPM bất
thường → **giai đoạn wet-start thành công**.

---

## Giai đoạn 7 — Tăng throttle (chạy thật có tải)

Chỉ làm khi IDLING đã ổn định. Lệnh throttle:

```
set throttle <0..100>
```

Cơ chế: `targetRpm = idleRpm + (maxRpm - idleRpm) * throttlePct / 100`,
ECU tự động chuyển `MODE_IDLING → MODE_OPERATING` khi `throttlePct > 0`
và closed-loop điều khiển bơm để đạt RPM mục tiêu.

**Quy trình tăng dần, không nhảy vọt**:

| Bước | Lệnh | Giữ tối thiểu | Quan sát |
|---|---|---|---|
| 7.1 | `set throttle 10` | 15-30s | RPM tăng nhẹ, EGT tăng từ từ, không dao động |
| 7.2 | `set throttle 25` | 15-30s | RPM ổn định ở target mới, EGT < maxEgtC |
| 7.3 | `set throttle 50` | 15-30s | Kiểm tra `rpmdetail` — jitter thấp, không NOISY |
| 7.4 | `set throttle 75` | 15-30s | EGT gradient theo dõi kỹ (dEGT) |
| 7.5 | `set throttle 100` | Chỉ khi đã quen động cơ | Full power — luôn sẵn sàng `stop` hoặc kill switch |

**Giảm ga về idle**: `set throttle 0` → tự động `MODE_OPERATING → MODE_IDLING`.

**Dừng máy an toàn (có làm mát)**: `stop` → vào `MODE_COOLDOWN`, starter
quay làm mát, tắt nhiên liệu/van, chờ `cooldownTargetC` rồi mới tắt hẳn.

**Dừng khẩn cấp**: nhấn kill switch vật lý (NC) — bypass hoàn toàn
firmware, ngắt điện trực tiếp. Lưu ý `set commwatchdog` sẽ tự abort nếu
mất kết nối Serial/Web quá `commTimeoutMs` lúc IDLING/OPERATING — xem
`CODE_REVIEW_FINDINGS.md`.

---

## Ma Trận Quyết Định GO/NO-GO (trước mỗi lần start engine thực)

| Hạng mục | GO | NO-GO |
|---|-----|---|
| EGT đọc nhiệt độ phòng (15-35°C) khi test tĩnh | ✅ | ❌ |
| RPM = 0 khi không quay (test tĩnh) | ✅ | ❌ |
| Giai đoạn 2B: toàn dải PWM đạt NOISE=CLEAN, STAB=STABLE | ✅ | ❌ |
| 9/9 Test Wizard PASS | ✅ | ❌ |
| Dry-start hoàn thành không lỗi | ✅ | ❌ |
| Không rò rỉ nhiên liệu, pump test khớp bảng calib | ✅ | ❌ |
| Kill switch đã confirmkill | ✅ | ❌ |
| SD card ghi log được | ✅ | ⚠️ Tùy chọn |
| Không có ABORT chưa được giải thích rõ | ✅ | ❌ |
| Nguồn/pin đủ dòng (đã đo sụt áp lúc test starter_ign) | ✅ | ❌ |

**Quy tắc GO**: tất cả ✅ trước khi nhấn `startidle` cho wet-start thật.

---

## Xử Lý Lỗi Thường Gặp

**RPM nhiễu cao (rejectPct > 20-30%)**
```
set rpmfilter 300
```
Lặp lại Giai đoạn 2B. Vẫn fail → kiểm tra wiring, thêm tụ 100nF tại GPIO33,
tách dây RPM xa dây công suất ESC. Vẫn fail → quay lại Giai đoạn 2A tăng
margin RP3.

**EGT không đọc được (FAULT/NaN)**
1. Kiểm tra thermocouple loại K, kết nối MAX31855 (CLK=18, CS=5, DO=19)
2. Đo điện áp cấp cho MAX31855
3. Thử thermocouple khác để loại trừ hỏng cảm biến

**Pump ESC không phản hồi**
1. Kiểm tra ESC arming (nghe beep khi cấp điện)
2. Đảm bảo nhận đúng tín hiệu PWM tại GPIO26
3. Đo PWM bằng oscilloscope/servo tester nếu nghi ngờ

**Starter chạy nhưng RPM không tăng**
1. Kiểm tra vị trí/hướng đặt sensor so với magnet (khoảng cách cố định ~5cm)
2. `rpmdetail on` — xem `raw` có tăng theo starter không
3. Kiểm tra nguồn 5V cho mạch RPM sensor (qua UBEC riêng)

**Starter khựng/giật giật rồi dừng dù firmware vẫn gửi PWM đều**
→ Đây là dấu hiệu **thiếu dòng cấp nguồn**, không phải lỗi firmware. Xem
phần "Nguồn & Pin" ở trên — đổi sang nguồn đủ dòng (ATX PSU, bench PSU,
hoặc pin LiPo đã tính margin phù hợp).

**Upload thất bại / không kết nối USB**
→ Xem phần "Cài Đặt Arduino IDE & Upload Firmware" ở trên.

---

## Nhật Ký Test (điền khi test thực tế)

```
Ngày test: _______________
Firmware: ECU_TestV1_EGT_DRY_START_PATCH
SD Log file: ECU___.CSV
Nhiệt độ phòng: ___°C

Giai đoạn 0 (đấu nối vật lý): PASS / FAIL
Giai đoạn 1 (test tĩnh): PASS / FAIL
Giai đoạn 2A (trimpot RP1/RP2/RP3): PASS / FAIL
  VTH_RPM tại điểm làm việc = _____ V
Giai đoạn 2B (quét PWM TEST_STARTER):
  rejectPct khi quay tay = ___%   NOISE cuối = _______
  Toàn dải CLEAN/STABLE? PASS / FAIL
Giai đoạn 3 (Test Wizard 9 bước): PASS / FAIL
Giai đoạn 4 (Pump test + confirmkill): PASS / FAIL
Giai đoạn 5 (Dry-start): PASS / FAIL
Giai đoạn 6 (Wet-start): PASS / FAIL
Giai đoạn 7 (Throttle tối đa đã test an toàn): ____%

GO / NO-GO cho lần chạy tiếp theo: _______

Ghi chú / Vấn đề gặp phải:
_______________________________________________
_______________________________________________
```

---

## Bảng Tóm Tắt Thứ Tự Toàn Bộ

```
0. Chuẩn bị an toàn + kiểm tra đấu nối vật lý
1. Test tĩnh: EGT, RPM_NOISE, SD                          → không quay gì
2. RPM sensor: 2A (trimpot DSO152) + 2B (quét PWM TEST_STARTER)
3. Test Wizard từng bộ phận (ign/starter/starter_ign/valve1/valve2)
4. Test bơm riêng (pumptest, không gắn engine) + confirmkill
5. Dry-start (quay thật, không nhiên liệu/lửa)
6. Wet-start (đánh lửa thật, có bước xả nhiên liệu tồn dư nếu fail) → IDLING ổn định
7. Tăng throttle từ 10% → 100% từng nấc, theo dõi EGT/RPM
```

---

## Lưu Ý An Toàn Xuyên Suốt

- **Không** dùng `set checklist off` khi test thật — chỉ dùng khi debug bench.
- **Không** dùng `clearabort force` trừ khi chắc chắn máy đã nguội và cảm
  biến EGT hỏng vĩnh viễn — lệnh này bỏ qua xác nhận nhiệt độ qua sensor.
- Sau **mọi ABORT**, đọc lý do (`lastAbortReason`) trước khi re-arm, đừng
  `clearabort` phản xạ.
- Sau `NO_IGNITION`/abort có phun dầu nhưng chưa cháy — xả nhiên liệu tồn
  dư (nghiêng đuôi xuống + quay rotor không tải) trước khi thử lại, xem
  Giai đoạn 6.
- Không gõ lệnh Serial chậm/ngắt quãng khi engine đang chạy thật.
- Không để SD đầy 1000 file log.
- Throttle luôn tăng/giảm từng nấc nhỏ, không set thẳng 100% từ IDLING.
- Nguồn/pin phải đủ dòng xả — nguồn yếu gây triệu chứng giống lỗi cơ khí
  (starter khựng) nhưng thực chất là thiếu dòng, xem phần "Nguồn & Pin".

---

**Tài liệu liên quan**:
- `PROJECT_CURRENT/Docs/CODE_ARCHITECTURE.md` — hiểu sâu kiến trúc firmware
- `PROJECT_CURRENT/Docs/CODE_REVIEW_FINDINGS.md` — các lỗi đã fix qua các vòng review, ảnh hưởng độ tin cậy các bước trên
- `REFERENCES/Documentation/Engine_Manual_E80_E100.pdf` — nguồn quy trình xả nhiên liệu tồn dư (Giai đoạn 6)
- `REFERENCES/Documentation/Engine_Manual_NewerModel.pdf` / `_Chinese.pdf` — manual EnJet G3/E86, nguồn valve1/valve2 role split
- `TEST/TEST_STARTER/TEST_STARTER.ino` — firmware bench dùng ở Giai đoạn 2B

**Phiên bản**: 3.1 — 2026-07-18 (gộp Upload/Test + Pre-Engine-Test + DSO152 + Commissioning thành 1 file)

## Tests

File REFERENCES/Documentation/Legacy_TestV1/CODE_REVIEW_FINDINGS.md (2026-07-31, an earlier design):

# Kết Quả Code Review - ECU_TestV1_EGT_DRY_START_PATCH.ino

**Ngày review**: 2026-07-16 (review gốc; xem các mục cập nhật cuối file cho thay đổi mới nhất)  
**File**: `ECU_TestV1_EGT_DRY_START_PATCH.ino` (~2290 dòng)  
**Trạng thái**: Sẵn sàng upload ESP32 — với lưu ý các vấn đề bên dưới

---

## 🔴 HIGH — Lỗi Logic An Toàn Nghiêm Trọng

### 1. `stage2Off()` không kiểm tra nhiệt độ EGT — Dòng 485
**Vấn đề**: Lệnh `off` qua Serial và nút "SAFE OFF" trên Web UI đều gọi `stage2Off()` → `enterWaitingSafe()` mà **không kiểm tra EGT còn nóng không**.  
**Nguy hiểm**: Sau khi bị ABORT do OVER_TEMP (EGT 650°C), operator có thể nhấn "SAFE OFF" → vào WAITING → re-arm ngay lập tức trong khi động cơ vẫn rất nóng.  
**Đường an toàn hiện tại**: Button vật lý kiểm tra `egtSafeForAbortClear()` (dòng 589) — nhưng Web UI thì không.  
**Khuyến nghị**: Thêm kiểm tra EGT vào `stage2Off()` trước khi gọi `enterWaitingSafe()`.

```cpp
// FIX gợi ý tại dòng ~485:
void stage2Off() {
  if (!egtSafeForAbortClear()) {
    Serial.println("STAGE2 OFF blocked: EGT still hot");
    return; // Không cho phép tắt khi EGT còn nóng
  }
  enterWaitingSafe();
}
```

---

### 2. Restart từ ABORTED không yêu cầu xác nhận lỗi — Dòng 1395
**Vấn đề**: `canStartAutoIdle()` cho phép start khi `ecuMode == MODE_ABORTED`. Chỉ kiểm tra EGT an toàn (dòng 1402), không yêu cầu operator xác nhận nguyên nhân abort (OVERSPEED, RPM_SIGNAL_LOST, v.v.).  
**Nguy hiểm**: Operator có thể gõ `startidle` ngay sau khi bị OVERSPEED abort — restart ngay mà không hiểu tại sao máy dừng.  
**Khuyến nghị**: Yêu cầu `clearAbort` command riêng trước `startidle`, hoặc tối thiểu log cảnh báo rõ ràng.

---

## 🟡 MEDIUM — Vấn Đề Ảnh Hưởng Đến Độ Tin Cậy

### 3. Pulse đầu tiên sau `resetRpmStats()` bỏ qua bộ lọc glitch — Dòng 740–745
**Vấn đề**: Trong ISR, khi `isrLastRawEdgeUs == 0` (sau `resetRpmStats()`), pulse đầu tiên được chấp nhận vô điều kiện, bất kể độ rộng.  
**Ảnh hưởng**: EMI spike từ igniter ở đầu giai đoạn `ST_SPINUP_PREHEAT` (wet start) có thể được đếm là RPM hợp lệ, che khuất thực tế starter không quay đủ.  
**Khuyến nghị**: Gọi `resetRpmStats()` trước cả wet start spin-up (tương tự dry start ở dòng 1457), không chỉ dry start.

### 4. `egt.gradientCps` bị stale khi EGT sensor lỗi — Dòng 882–886
**Vấn đề**: Khi `egt.ok = false`, biến `gradientCps` không được reset về 0. Các hàm control đọc `egt.ok` trước (an toàn), nhưng Web UI `/api` và `printStatus()` hiển thị gradient cũ mà không đánh dấu là invalid.  
**Ảnh hưởng**: Operator thấy gradient đang hiển thị "30 °C/s" nhưng thực ra EGT sensor đã bị lỗi từ lâu — gây nhầm lẫn khi debug.  
**Khuyến nghị**: Reset `egt.gradientCps = 0` khi `egt.ok = false` trong `updateEgt()`.

### 5. `Serial.readStringUntil('\n')` có thể block loop tới 1 giây — Dòng 1897
**Vấn đề**: Hàm `readStringUntil` chờ đến 1000ms nếu không có newline (gõ chậm, kết nối bị ngắt quãng).  
**Ảnh hưởng**: Trong 1 giây đó, `updateEgt()`, `updateRpm()`, `checkFailures()`, và `applyOutputs()` đều không chạy — **mất phản hồi an toàn trong 1 giây**.  
**Khuyến nghị**: Thay bằng non-blocking serial command buffer, đọc từng ký tự với `Serial.read()` và chỉ xử lý khi có `\n`.

---

## 🟢 LOW — Cải Tiến Nhỏ

### 6. SD file slot bị đầy → ghi đè file cũ — Dòng 995–998
Nếu đã có đủ 1000 files (ECU000.CSV đến ECU999.CSV), vòng lặp tìm tên file kết thúc với `i=999` vẫn trỏ vào file có sẵn. Header mới sẽ được append vào cuối file đó, làm hỏng log cũ.

### 7. Double SPI read → fault code có thể sai — Dòng 880–881
`thermo.readCelsius()` và `thermo.readError()` là 2 transaction SPI riêng biệt. Nếu lỗi thoáng qua giữa 2 lần đọc, `egt.fault = 0` trong khi `egt.ok = false` → hiển thị "SPI/WIRING" thay vì tên lỗi thực.

### 8. Jitter metric bị phóng đại bởi một outlier — Dòng 846–847
`jitterPct = (maxDt - minDt) / avgInterval * 100`. Một khoảng dài bất thường duy nhất trong cửa sổ 100ms làm jitter tăng cao sai, có thể báo `RPM_WARN` / `RPM_NOISY` khi tín hiệu thực ra sạch — có thể block start qua `rpmNoiseBlocksStart()`.

---

## ✅ Điểm Tốt — Giữ Nguyên

| Tính năng | Đánh giá |
|---|---|
| REST RPM guard | Xuất sắc — loại bỏ false pulse khi mọi output OFF |
| Dry-start khi EGT OPEN | Đúng và an toàn — chạy starter, tắt nhiên liệu/van |
| `egtAllowsFuelIncrease()` lookahead 3s | Logic rõ ràng, đúng |
| ACCEL_TO_IDLE timeout 20s | Cần thiết, được implement tốt |
| Cooldown với starter chạy | Đúng — làm mát sau stop |
| Glow preheat trước khi có nhiên liệu | Đúng (SPINUP_PREHEAT → ignCmd=true trước fuel) |
| Pump calibration table | Khớp chính xác với đo thực tế |
| ISR `IRAM_ATTR` | Đúng — ISR trong IRAM |
| Button 2-step ARM→START | An toàn |

---

## 📊 Điểm An Toàn Tổng Thể (lúc review ban đầu, trước khi fix)

| Hạng mục | Điểm |
|---|---|
| Logic state machine | 8/10 |
| EGT safety guards | 7/10 *(vấn đề #1 Web UI)* |
| RPM noise handling | 8/10 *(vấn đề #3, #8)* |
| Fuel control safety | 9/10 |
| Serial/Web interface safety | 6/10 *(vấn đề #2, #5)* |
| **Tổng** | **7.5/10** |

**Cập nhật**: cả 8 vấn đề trên đã được fix (xem checklist bên dưới) — bảng
điểm này chỉ còn giá trị lịch sử, không phản ánh trạng thái code hiện tại.

---

## 🚀 Quyết Định: Có Upload ESP32 Được Không?

**YES — đã fix toàn bộ 8/8 vấn đề vòng 1** (trước đây có 4 ràng buộc vận
hành tạm thời cho #1/#2/#5/#6, nay không còn cần thiết vì các lỗi gốc đã
được fix trong code thay vì né bằng quy trình vận hành).

---

## 📋 Fix Priority

```
Fix ngay (trước lab test):
[x] #5 Non-blocking serial command buffer

Fix trước engine test thực sự:
[x] #1 EGT guard trong stage2Off()
[x] #2 Require clearAbort trước startidle
[x] #3 resetRpmStats() trước wet start spin-up

Fix sau (ít quan trọng hơn):
[x] #4 Reset gradientCps khi EGT invalid
[x] #6 SD slot overflow handling — không còn ghi header mới đè vào ECU999.CSV khi đầy 1000 slot
[x] #7 Single SPI read cho readCelsius + readError — đổi thứ tự đọc readError() trước
[x] #8 Dùng stddev thay max-min cho jitter — coefficient of variation, không bị 1 outlier làm sai
```

**Tất cả 8 lỗi vòng 1 đã fix (2026-07-16).** Compile sạch (`g++ -fsyntax-only
-Wall -Wextra`, không warning).

---

# 🔁 Review Vòng 2 (2026-07-16) — 9 lỗi mới, đã fix toàn bộ

Sau khi fix 8 lỗi vòng 1, chạy thêm một vòng review sâu (8 finder angles +
verify) và tìm được **9 lỗi mới**. Tất cả đã được fix và firmware đã
compile sạch (`g++ -fsyntax-only -Wall -Wextra`, không warning).

## 🔴 CRITICAL — An toàn nhiên liệu

| # | Vị trí | Lỗi | Cách fix |
|---|---|-----|---|
| 1 | `pumptest` / `test pump` | Mở van + bơm nhiên liệu khi ở MODE_ABORTED mà không kiểm tra EGT → có thể phun nhiên liệu vào buồng đốt còn nóng sau abort OVER_TEMP | Thêm `fuelCommandBlockedByHotEgt()`: chặn khi EGT đọc được và > `cooldownTargetC` |
| 2 | `checkFailures()` | Guard RPM_SIGNAL_LOST bỏ sót `ST_INTRO_FUEL`/`ST_POST_IGNITION_HEAT` → mất tín hiệu RPM khi van nhiên liệu đang mở không bị abort trong tối đa 6s | Guard mới bao trùm cả `MODE_STARTING` (mọi stage có nhiên liệu) |

## 🟠 HIGH — Độ tin cậy RPM & state machine

| # | Vị trí | Lỗi | Cách fix |
|---|---|-----|---|
| 3 | `rpmISR()` | Glitch bị reject vẫn cho glitch kế tiếp lọt qua filter → phantom RPM → có thể kích OVERSPEED giả | Thêm **adaptive mask**: reject cạnh đến sớm hơn ½ chu kỳ hợp lệ gần nhất (turbine không thể tăng đôi tốc độ trong 1 vòng) |
| 4 | `updateRpm()` | `nowUs = micros()` lấy trước `noInterrupts()` → ISR chen giữa gây wraparound uint32 → `signalRecent=false` giả → abort RPM_SIGNAL_LOST oan | Dời `micros()` ra **sau** critical section (đảm bảo `nowUs >= lastPulseUs`) |
| 5 | `egtSafeForAbortClear()` | Cảm biến EGT hỏng vĩnh viễn (`egt.ok=false`) chặn TẤT CẢ đường thoát MODE_ABORTED → kẹt cứng, phải cúp nguồn | Thêm `egtAllowsDeliberateAbortClear()` + lệnh `clearabort force` (chỉ dry-start sau đó) |
| 6 | `beginAutoIdle()` | Không xóa `activeTest`/`activeTestEndMs` → timer test đang chạy bắn giữa chu trình start thật, dừng starter | Xóa `activeTest = TEST_NONE; activeTestEndMs = 0;` khi bắt đầu start |
| 7 | `ST_INTRO_FUEL` dòng 1542 | Check NO_RPM_RISE (`fuelConfirmTimeoutMs`=10s) là **dead code** vì NO_IGNITION (6s) luôn abort trước | Chuyển check sang neo theo `ignitionDetectedMs`, chạy trong POST_IGN + ACCEL_TO_IDLE (`checkPostIgnitionRpmRise()`) |

## 🟡 MEDIUM — Hiệu năng / độ bền

| # | Vị trí | Lỗi | Cách fix |
|---|---|-----|---|
| 8 | `sdAppendLine()` | SD open/close đồng bộ mỗi event → block main loop 10–100ms trên thẻ chậm, trễ `checkFailures()` | Hàng đợi SD event: snapshot lúc phát sinh, ghi (blocking) trong loop **sau** safety check |
| 9 | `webStatusJson()` | ~25 lần `String +=` không `reserve()` → phân mảnh heap mỗi 700ms poll → nguy cơ Guru Meditation | Thêm `s.reserve(896)` |

## ✅ Kết luận vòng 2

- Firmware **compile sạch** với mock ESP32/Servo/MAX31855/WiFi/WebServer/SD.
- Đã trace toàn bộ luồng: `WAITING → PURGE → SPINUP_PREHEAT → INTRO_FUEL
  (đánh lửa) → POST_IGNITION_HEAT → ACCEL_TO_IDLE → IDLING`. Các fix
  **không phá vỡ** luồng chạy tới đánh lửa và idle.
- Các interlock để chạy wet start thật: `arm2` → `autostart on` → chạy đủ
  Test Wizard + `confirmkill` → `startidle`.

**Còn lại (tùy chọn, không chặn test)**: dry-start hiện bỏ qua toàn bộ
checklist kể cả `TEST_KILL` — cân nhắc vẫn yêu cầu xác nhận kill switch cho
dry-start vì starter vẫn quay trục thật (rủi ro thấp: dry-start không có
nhiên liệu/lửa).

---

# 🔁 Review Vòng 3 (2026-07-16) — So sánh với Rev11/Rev12_TC10, 2 lỗi đã fix

So sánh cấu trúc + an toàn với 2 bản firmware tham khảo
(`REFERENCES/Firmware/Rev11`, `REFERENCES/Firmware/Rev12_TC10`). Kết luận
chung: firmware hiện tại **an toàn hơn** cả 2 bản tham khảo ở mọi interlock
cốt lõi (abort cứng, cooldown thật, ARM/START 2 bước, RPM noise
classification, Test Wizard checklist). Tuy nhiên tìm được 2 khoảng trống
so với Rev11/12, cả 2 đã được fix:

| # | Vị trí | Lỗi | Cách fix |
|---|---|-----|---|
| 1 | Không có tương đương RC-signal-loss failsafe của Rev11/12 | `throttlePct` là giá trị chốt qua lệnh Serial/Web rời rạc; nếu mất kết nối Web UI/Serial giữa lúc `MODE_IDLING`/`MODE_OPERATING`, động cơ chạy mãi ở ga cuối cùng không ai giám sát | Thêm **comm watchdog**: `lastOperatorLinkMs` cập nhật ở mọi lệnh (`handleCommand()`) và mỗi lần Web UI poll `/api` (tự động mỗi 700ms khi tab mở). `checkFailures()` tự abort `COMM_TIMEOUT` nếu quá `cfg.commTimeoutMs` (mặc định 8000ms, chỉnh qua `set commtimeout <3000..60000>`) không có tín hiệu nào trong lúc IDLING/OPERATING. Tắt qua `set commwatchdog off` yêu cầu `arm2` trước (debug only) |
| 2 | `abortAll()` → `enterCooldown()` | Log snapshot lúc abort bị ghi **sau khi** `enterCooldown()` đã zero hóa `fuelTargetUs`/`pumpUs`/`ignCmd`/`startUs` → SD/event log thể hiện giá trị đã an toàn hóa, không phải giá trị thật lúc lỗi xảy ra, làm giảm giá trị chẩn đoán sự cố | `abortAll()` gọi `addLog("ABORT_SNAPSHOT reason=...")` **trước** khi gọi `enterCooldown()`, chụp đúng RPM/EGT/fuel/outputs tại thời điểm lỗi |

**Verify**: compile sạch (`g++ -fsyntax-only -Wall -Wextra`, mock ESP32/Servo/
MAX31855/WiFi/WebServer/SD, không warning).

---

# 🔧 Cập nhật vai trò Valve1/Valve2 (2026-07-16) — theo manual EnJet E86/G3

Đối chiếu `REFERENCES/Documentation/Engine_Manual_NewerModel.pdf` (EnJet G3
Series manual, có bảng thông số E86) xác nhận động cơ dùng **2 valve dầu**
(không phải gas): **Start solenoid valve** (mạch dầu khởi động riêng) +
**Main oil valve** (mạch dầu chính, luôn mở khi bơm chạy — theo mô tả
"Oil Pump Test" tự động liên kết mở Main valve trong manual).

Trước đây `fuelValvesAuto()` mở/đóng cả 2 valve đồng thời, không phân biệt
vai trò. Đã cập nhật:

```cpp
void fuelValvesAuto(bool on) {
  valve2Cmd = on;                              // Main: mở bất cứ khi nào có lệnh nhiên liệu
  valve1Cmd = on && (ecuMode == MODE_STARTING); // Start: chỉ mở trong lúc MODE_STARTING
}
```

- **VALVE1 (Start)** chỉ mở trong `ST_INTRO_FUEL → ST_POST_IGNITION_HEAT →
  ST_ACCEL_TO_IDLE` (toàn bộ `MODE_STARTING`), tự động đóng ngay khi chuyển
  sang `MODE_IDLING`.
- **VALVE2 (Main)** giữ hành vi cũ — mở bất cứ khi nào `fuelValvesAuto(true)`
  được gọi, bất kể mode (khớp `pumptest`/Test Wizard pump-prime = "Oil Pump
  Test" của Enjet, chỉ mở Main).
- Checklist đổi tên hiển thị `VALVE_1`→`VALVE1_START`, `VALVE_2`→`VALVE2_MAIN`
  để rõ vai trò trên Serial/Web UI.
- Đã rà soát toàn bộ điểm gọi `valve1Cmd`/`valve2Cmd` (rest-guard, fueled
  check trong `checkFailures()`, log) — không có điểm nào phụ thuộc hành vi
  "2 valve luôn giống nhau" nên không có tác dụng phụ.

**Lưu ý còn để ngỏ**: giả định trên dựa vào tài liệu chính hãng, chưa xác
nhận vật lý E86 đời cũ của người dùng có đúng 2 mạch dầu tách biệt hay
không — nên đối chiếu lại đường ống thật trước khi test có nhiên liệu.

**Verify**: compile sạch (`g++ -fsyntax-only -Wall -Wextra`, không warning).

---

# 🔧 ESP32Servo → LEDC + Starter Kick + Web UI cho TEST_STARTER (2026-07-17)

## Bối cảnh

Test bench với nguồn 12V 2A: starter khựng/giật giật rồi dừng dù firmware
vẫn gửi PWM đều đặn. Ban đầu chẩn đoán là thiếu dòng cấp nguồn (đúng, xem
mục "Nguồn & Pin" trong `COMMISSIONING_GUIDE.md`), nhưng người dùng thử
nghiệm 1 sketch riêng dùng LEDC PWM trực tiếp (không qua thư viện
`ESP32Servo`) — **chạy êm với CÙNG một nguồn 12V 2A**. Điều này cho thấy
`ESP32Servo` là một nguyên nhân riêng biệt, độc lập với nguồn điện — xem
chi tiết kỹ thuật trong `CLAUDE.md` ở gốc repo.

## Thay đổi

| # | File | Thay đổi |
|---|---|---|
| 1 | `ECU_TestV1_EGT_DRY_START_PATCH.ino` | Bỏ `ESP32Servo`, chuyển pump+starter ESC sang LEDC PWM trực tiếp (`escAttach()`/`escWriteUs()`, tương thích cả ESP32 Arduino core 2.x và 3.x qua `ESP_ARDUINO_VERSION_MAJOR`) |
| 2 | `ECU_TestV1_EGT_DRY_START_PATCH.ino` | Thêm **starter kick**: `cfg.starterKickUs`/`cfg.starterKickMs` — xung cao ngắn (mặc định 1300us/300ms) ngay đầu `ST_PURGE` trước khi hạ về `starterPurgeUs`, giúp starter có cơ cấu Bendix/clutch ăn khớp dứt khoát. Lệnh mới: `set starterkickus`, `set starterkickms` |
| 3 | `ECU_TestV1_EGT_DRY_START_PATCH.ino` | Web UI dashboard: thêm mục "Starter Kick" (chỉnh kickUs/kickMs) và "Starter Manual Test" (chạy `starttest <us> <ms>` từ trình duyệt) |
| 4 | `TEST/TEST_STARTER/TEST_STARTER.ino` | Cùng 3 thay đổi trên: LEDC thay ESP32Servo, thêm kick (`kickus`/`kickms`), và thêm **Web UI đầy đủ** (SoftAP `TEST_STARTER`/`test1234`, dashboard + toàn bộ lệnh qua nút/ô nhập) — cho phép test không cần Serial Monitor |

**Verify**: compile sạch cả 2 file (`g++ -fsyntax-only -Wall -Wextra`, không warning).

**Lưu ý**: `starterKickMs=0` tắt hoàn toàn tính năng kick nếu không cần.

---

# 🔧 Gỡ starter kick + tăng giá trị test (2026-07-18)

Theo yêu cầu: **bỏ hẳn tính năng starter kick** (không cần công đoạn này nữa)
và nâng giá trị test.

| # | File | Thay đổi |
|---|---|---|
| 1 | `ECU_TestV1_EGT_DRY_START_PATCH.ino` | Gỡ `cfg.starterKickUs`/`cfg.starterKickMs`, helper `starterKickOrSteady()`, 2 lệnh `set starterkickus`/`set starterkickms`, mục Web UI "Starter Kick", và dòng in trong printConfig/printHelp. `ST_PURGE` (cả start thật lẫn dry-start) giờ dùng thẳng `starterPurgeUs` |
| 2 | `ECU_TestV1_EGT_DRY_START_PATCH.ino` | **starterSpinUs 1150 → 1200** (test wizard "Starter" + spin thật + default Web UI "Starter Manual Test"). **introFuelUs 1160 → 1210** (pump prime test + intro fuel thật). Nới trần bench `pumptest` 1175 → **1225µs** để đạt mức mới |
| 3 | `TEST/TEST_STARTER/TEST_STARTER.ino` | Gỡ toàn bộ kick (globals, `applyPwm`/`setPwm`, lệnh `kickus`/`kickms`, trường JSON, mục Web UI, docstring). Default PWM Web UI 1150 → 1200 |

> ⚠️ **ĐÃ THAY ĐỔI SAU (superseded)**: hàng #2 để `introFuelUs=1210` gây `introFuelUs > idleFuelUs`
> (khởi động quá giàu). Xem mục **2026-07-18 (review toàn project)** bên dưới: `introFuelUs`
> đã khôi phục về **1160** (< idle) và giá trị pump test **1210** tách sang biến riêng `pumpTestUs`.

**Lưu ý (đã lỗi thời — xem ghi chú trên)**: `introFuelUs`(1210) từng > `idleFuelUs`(1175)
theo quyết định "đổi cả config chung"; nay đã tách `pumpTestUs`.

**Không hard-code — chỉnh runtime**: các mức PWM starter/fuel giờ đổi được lúc
chạy, không cần build lại firmware:
- Lệnh mới: `set purgeus <us>`, `set spinus <us>`, `set assistus <us>` (1000..1500)
  cho starterPurge/Spin/Assist. `set intro`/`set idleus`/`set maxus` đã có sẵn.
- Web UI: thêm panel **"Starter & Fuel PWM"** với ô nhập cho purge/spin/assist +
  intro/idle/max, mỗi ô có nút Set gọi lệnh tương ứng.
- `printConfig` in thêm dòng `starter purge/spin/assist us=...`.
- Giá trị trong Config struct chỉ còn là **mặc định lúc khởi động**, ghi đè
  được bất cứ lúc nào qua Serial hoặc trình duyệt.

**Verify**: compile sạch cả 2 file (`g++ -fsyntax-only -Wall -Wextra`, không
warning) + mô phỏng chèn auto-prototype kiểu Arduino cho firmware chính (OK).

---

# 🔎 Review toàn project + fix an toàn (2026-07-18)

Review 4 mảng bằng agent song song (state machine, cảm biến/ISR/EGT/fuel,
Web UI/SD/command, TEST_STARTER). Xác nhận **không** có đọc ISR uint64 hở,
**không** chia 0, LEDC duty đúng, gỡ kick sạch. Đã fix các lỗi sau:

**HIGH**
- **#1/#2 Web UI default lệch config**: `Max EGT` hiển thị 780 (config 680),
  `Idle RPM` 32000 (config 42000) → bấm Set là âm thầm đổi ngưỡng bảo vệ.
  Fix: sửa default khớp config **và** thêm field `cfg*` vào `/api`, JS `setInp()`
  tự nạp mọi ô tune từ config mỗi poll (không ghi đè khi đang gõ).
- **#3 `stop` từ ABORTED** xóa lý do lỗi + quay starter, rò ABORTED→WAITING bỏ
  qua interlock. Fix: `requestStop()` chỉ tác dụng khi STARTING/IDLING/OPERATING.
- **#4 Start bằng nút bị comm-watchdog abort ngay khi vào IDLING**. Fix: cờ
  `runStartedByButton` (bỏ qua watchdog cho run bằng nút; re-engage khi có lệnh
  remote) + reset `lastOperatorLinkMs` trong `beginAutoIdle`.
- **#5 Lệnh `set` an toàn không bị chặn khi chạy**. Fix: chặn tune PWM/limit
  (intro/idleus/maxus/pumptestus/purgeus/spinus/assistus/idlerpm/maxrpm/rpmtol/
  maxegt) — chỉ nhận khi WAITING/ABORTED.

**MEDIUM**
- **#6/#7 intro>idle + pump test ~3x fuel**: **tách** `pumpTestUs`(1210, bench
  prime) khỏi `introFuelUs`(khôi phục 1160 < idle). `test pump` dùng `pumpTestUs`;
  thêm `set pumptestus` + ô Web UI; sửa comment/thông báo flow.
- **#11 `off` từ ABORTED** rời ABORTED không set ack. Fix: `stage2Off()` ở ABORTED
  chỉ re-assert safe, yêu cầu `clearabort`.
- **#9 SD telemetry blocking**: `sdAppendLine` đếm lỗi liên tiếp, sau 5 lần đặt
  `sdOk=false` (ngừng block loop khi rút thẻ). *(Slow-card vẫn cần task riêng.)*

**LOW**
- **#15** nới `webStatusJson reserve` 896→2048, `sdCsvLine` 240→320.
- **#16** `valve1/valve2 on` auto-off sau 10s (`VALVE_TEST_TIMEOUT_MS`).

**Còn để lại (chưa fix, low)**: #10 watchdog thỏa mãn bởi auto-poll, #12
overspeed/flameout gate sau NOISY (được RPM_SIGNAL_LOST cứu), #14 SoftAP mật khẩu
yếu, #17 ABORTED chưa chặn EGT nóng cho ign/starter, #18 không phát hiện EGT
đóng băng, #19 micros()==0 sentinel, #20 jsonEscape control chars.

**Verify**: compile sạch (`g++ -fsyntax-only -Wall -Wextra`) + mô phỏng
auto-prototype Arduino cho firmware chính.

---

# 🔎 Quét toàn project vòng 2 + fix logic điều khiển (2026-07-18b)

Quét lại bằng 3 agent (hồi quy PR #17, correctness mới, docs↔code). Xác nhận PR #17
đúng, không hồi quy; TEST_STARTER không bug. Fix thêm các lỗi logic điều khiển:

**Logic điều khiển (#1–4)**
- **#1** Soft cut quá nhiệt trước đây chỉ ~2µs/s (không kịp) → khi `egtRequestsFuelCut()`
  giờ hạ `pumpUs` theo bước `fuelCutStepUs` ở nhịp decel nhanh (~40µs/s), vẫn có hard
  OVER_TEMP làm net cuối.
- **#2** `updateOperating`: governor full-throttle nhắm `maxRpm - rpmTolerance` (không
  còn tự kích OVERSPEED ở 100% throttle).
- **#3** RPM-loss khi IDLING/OPERATING dùng `FUELED_RPM_LOSS_TIMEOUT_MS=400ms` (thay 1s)
  → cắt nhiên liệu nhanh sau flameout thật.
- **#4** Grace flameout neo vào `runningSinceMs` (idle ổn định đầu tiên), không reset khi
  gạt throttle IDLING↔OPERATING.

**Tuning/robustness (#5–8)**
- **#5** Trong `MODE_STARTING`, bỏ chặn theo gradient/look-ahead 3s (rise lúc light-off là
  bình thường) — chỉ còn `maxEgtC` tuyệt đối + look-ahead ngắn của abort. Thêm `set maxgrad`.
- **#6** RPM_SIGNAL_LOST lúc STARTING chỉ dựa vào "có xung gần đây" (recency), không dựa
  vào phân loại NOISY → nhiễu ign lúc light-off không abort oan; sensor chết vẫn bắt được.
- **#7** Comm watchdog phủ cả `MODE_STARTING` khi đã có nhiên liệu (không phủ PURGE/SPINUP khô;
  run bằng nút vẫn miễn).
- **#8** OVER_TEMP abort thêm look-ahead ngắn `EGT_ABORT_LOOKAHEAD_S=0.2s` bù trễ ~1 mẫu EGT.

**Docs/cosmetic**: bỏ `ESP32Servo` khỏi README; sửa số dòng/ngày; ghi chú superseded cho
mục introFuelUs=1210; zero timer valve trong forceSafeOutputs; nới reserve JSON 2048→2560.

**Verify**: compile sạch (`g++ -fsyntax-only -Wall -Wextra`, không warning) + mô phỏng
auto-prototype Arduino (OK).

> **Cần validate trên động cơ thật**: tốc độ cắt nhiên liệu #1, ngưỡng governor #2, các
> giá trị timeout/gradient #3/#5/#8 nên được kiểm chứng bằng lần chạy thật và tinh chỉnh
> qua `set ...`.

---

# 🔻 Xử lý nốt các mục LOW (2026-07-18c)

- **#17** Chặn `ignpulse` và `valve1/valve2 on` khi EGT còn nóng (`fuelCommandBlockedByHotEgt`)
  — không cho châm lửa/mở van vào lõi nóng ở ABORTED. `starttest` (chỉ starter, giúp làm mát) giữ nguyên.
- **#18** Cảnh báo **log-only** (không abort) khi EGT đứng yên byte-for-byte > `EGT_STUCK_WARN_MS`
  lúc đang cháy → gợi ý thermocouple đóng băng (loại lỗi mà fault open/short không bắt được).
- **#19** ISR ép `micros()` khác 0 (bỏ va chạm sentinel "chưa có cạnh" mỗi ~71 phút) — cả 2 firmware.
- **#20** `jsonEscape` xử lý mọi ký tự control (`\r`/`\t`/`\u00XX`) → JSON không vỡ.
- **#14** Thêm ghi chú bảo mật + đánh dấu `WEB_PASS` cần đổi trước khi chạy thật (cả 2 firmware);
  không tự đổi mật khẩu (giữ credential người dùng đang dùng).
- **#10** `/api` chỉ tính là "operator hiện diện" khi tab đang hiển thị (client gửi `act=0` khi
  ẩn/khoá màn hình) → phiên bỏ đi sẽ time-out thay vì bị auto-poll giữ sống mãi. Tương thích ngược.
- **#12** Không sửa: overspeed/flameout khi NOISY đã được `RPM_SIGNAL_LOST` bao (NOISY + có nhiên
  liệu → abort cắt nhiên liệu), nên đã an toàn.

**Verify**: compile sạch (`g++ -fsyntax-only -Wall -Wextra`) + mô phỏng auto-prototype Arduino.

---

# 🔎 Quét toàn project vòng 3 (2026-07-18d)

Quét lại bằng 2 agent (correctness + hồi quy toàn firmware; TEST_STARTER + đối chiếu
doc↔code). Xác nhận: **các fix vòng 1–2 đúng, không hồi quy**; **TEST_STARTER không bug**;
`CODE_ARCHITECTURE.md` khớp code (chỉ 3 chỗ chữ nghĩa nhỏ đã vá). Fix 3 điểm mới:

- **#1 `set cooldownms` hỏng**: `parseTwoInts` cắt theo dấu cách đầu tiên nhưng lệnh có
  prefix 3 từ → `minMs` parse nhầm thành 0 → luôn báo lỗi. Sửa: parse riêng 2 số sau prefix.
- **#2 `off`/SAFE-OFF lúc COOLDOWN-sau-abort** lọt sang WAITING (xóa lý do lỗi, bỏ qua
  `clearabort`, cắt luôn airflow làm mát). Sửa: `stage2Off()` bỏ qua khi
  `MODE_COOLDOWN && cooldownAfterAbort` → để cooldown chạy hết vào ABORTED.
- **#3 RPM_SIGNAL_LOST abort oan động cơ đang chạy** (có sẵn): NOISY do `rejected≥3` tuyệt
  đối trong 1 cửa sổ 100ms có thể tắt máy khoẻ. Sửa: **debounce** NOISY-nhưng-còn-xung ở
  IDLING/OPERATING — chỉ abort nếu kéo dài ≥ `RPM_NOISY_ABORT_MS` (300ms); mất xung thật
  (recency 400ms) vẫn abort ngay.

**Verify**: compile sạch (`g++ -fsyntax-only -Wall -Wextra`) + mô phỏng auto-prototype Arduino.

---
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

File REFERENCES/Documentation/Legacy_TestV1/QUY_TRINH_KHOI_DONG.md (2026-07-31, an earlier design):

# Quy Trình Khởi Động (RPM-gated ignition)

Tài liệu mô tả trình tự khởi động động cơ đã triển khai trong
`ECU_TestV1_EGT_DRY_START_PATCH.ino`. **Mọi giá trị (xung, tốc độ, thời gian,
ngưỡng)** đều chỉnh được trong **Web UI → Settings** và **lưu vào thẻ SD**
(`/ECUCFG.TXT`, nút "Lưu config vào SD"), tự nạp lại khi bật máy.

## Giai đoạn 1 — PURGE
PURGE gồm **3 bước** (dùng chung hàm ramp cho cả dry test lẫn chạy thật):
1. **ESC arm-hold**: giữ starter ở **ESC_SAFE (1000µs, thật sự = 0)** trong
   **2s (`escarmholdms`)** đầu tiên để ESC hoàn tất tự chuỗi "arm" của nó trước khi
   nhận bất kỳ xung khác 0 nào — nếu nhảy thẳng lên 1150µs ngay lập tức, ESC có thể
   mới arm được một phần, biểu hiện ra ngoài giống như "quay vài vòng rồi khựng".
2. Giữ nguyên **1150µs (`rampfromus`)** trong **10s (`purgestablems`)** để chạy ổn định.
3. **Sau đó mới tăng xung +1µs mỗi 250ms (≈ 4µs/s = 2µs/0.5s)**, tới khi **RPM > 3000**
   thì **giữ 3s** để thổi sạch khí/dầu dư, rồi sang giai đoạn kế.

Chưa glow, chưa nhiên liệu. Nếu quá `spinuptimeoutms` (57s, đã tính cả 2s arm-hold +
10s ổn định) mà RPM chưa đạt → abort `NO_RPM`. Điều kiện abort do thiếu RPM starter
(`STARTER_PROVE_TIMEOUT_MS`, 1.5s) chỉ bắt đầu tính **sau khi hết `escarmholdms`**
(RPM = 0 trong lúc arm-hold là bình thường, không phải lỗi starter).

## Giai đoạn 2 — SPINUP_PREHEAT
**Bật glow plug 2s** để làm nóng, sau đó **vẫn giữ glow bật** và sang giai đoạn kế.
Starter chuyển sang chế độ trợ lực theo RPM (xem "ánh xạ starter").

## Giai đoạn 3 — INTRO_FUEL
Glow đang bật. **Bơm nhiên liệu ở mức min (1015µs)** + **mở Start Valve (Valve 1)**.
Sang giai đoạn kế (LIGHTOFF).

## Giai đoạn 4 — LIGHTOFF (mồi lửa + sang van)
- Chờ **~1s (fuel delay)** để nhiên liệu tới buồng đốt.
- **Xác nhận bắt lửa THẬT** (tránh false light-off do glow làm nóng cặp nhiệt mà chưa
  cháy): **EGT ≥ 100°C VÀ dEGT/dt ≥ `lightoffrise` (mặc định 15°C/s), giữ liên tục
  ≥ `lightoffconfirmms` (0.7s)**. → Mở **Main Valve (Valve 2)**.
- Chờ **2s** (`postIgnitionHeatMs`) cho lửa ổn định → **đóng Start Valve (Valve 1)**.
- Chờ thêm **2s** (`flameProveMs`) xem lửa còn cháy (không mất lửa) → **tắt glow**,
  đánh dấu **khởi động thành công**, sang ACCEL_TO_IDLE.
- **Thất bại**: nếu quá **6s** (`noIgnitionTimeoutMs`) mà chưa xác nhận bắt lửa, hoặc
  **mất lửa** trong lúc sang van → tắt glow + bơm + van, đánh dấu **thất bại**, và giữ
  starter chạy (blow-out) trong `purgeoutms` để thổi hết nhiên liệu chưa cháy, rồi cooldown.

## Giai đoạn 5 — ACCEL_TO_IDLE
Chỉ Main Valve (Valve 2), glow tắt. Nếu lửa còn cháy mà **RPM không tăng** thì
**tăng xung bơm +1µs, chờ 5s** quan sát RPM, lặp cho tới khi đạt **idle RPM (42000)**.
(Bước/thời gian là giá trị test, sẽ tăng nhanh hơn khi tìm được thông số phù hợp.)

## Ánh xạ starter theo RPM (trợ lực)
Từ SPINUP_PREHEAT trở đi, xung starter bám theo RPM:
```
startUs = assistMin + (assistMax − assistMin) × (rpm / releaseRpm)   [kẹp assistMin..assistMax]
rpm ≥ releaseRpm (10000)  →  starter OFF (nhả cánh quạt)
```
- `assistMin` = `Assist us` (≈1150µs) — xung khi RPM thấp
- `assistMax` = `Ramp to us` (**1450µs**) — xung tối đa
- `releaseRpm` = `Starter max RPM` (**10000**) — điểm nhả starter, tránh quá tải motor đề

## Bảo vệ (chạy mọi lúc, mọi mode)
1. **Chống quá tải starter**: RPM > **10000** → starter **tắt** (nhả cánh quạt, để RPM tự
   tăng lên idle).
2. **Chống soak-back nhiệt**: nếu **EGT > 90°C** mà **RPM < 3000** → starter tự chạy,
   **bắt đầu 1200µs, tăng +1µs/0.1s** (không giật từ 1150µs) tới khi RPM > 3000 rồi giữ,
   cho tới khi **EGT < 90°C** thì mới dừng — tránh khí nóng dội ngược lên đầu máy khi
   động cơ nóng bị dừng/tụt tua.
3. **Quá nhiệt**: EGT ≥ maxEgt (680°C, có look-ahead) → abort ngay (áp dụng cả khi start).

## Tiêu chí mất lửa (flame-out)
**EGT tụt > 10°C trong ~2s HOẶC EGT < 100°C** (hoặc cặp nhiệt lỗi) → coi là mất lửa.

## Tham số tune (Web UI → Settings → "Tune — Start sequence")
`rampfromus`, `ramptous` (assist max), `rampstepms`, `escarmholdms`, `purgestablems`, `ignarmrpm`, `spinuptimeoutms`,
`fueldelayms`, `lightoffrise`, `lightoffconfirmms`, `flameprovems`, `flameoutdropc`,
`accelholdms`, `accelstepus`, `purgeoutms`; và "Bảo vệ động cơ/starter":
`startermaxrpm`, `hotspinminrpm`, `hotspinus`, `cooltarget` (90°C).

> ⚠️ **Chưa kiểm chứng trên phần cứng.** Cần bench-test toàn bộ trình tự + các cơ cấu
> bảo vệ, và **đo lại bảng lưu lượng bơm `kPumpMap`** dưới xung LEDC trước khi start thật.

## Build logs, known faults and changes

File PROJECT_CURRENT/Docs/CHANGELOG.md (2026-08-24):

# Ardu ECU Manual V1 - Changelog & Version History

## [v8.0] - 2026-08-24
- **CI/CD Auto Release**: Automatically incremented version to v8.0.
- Synchronized Web UI v8.0 and Firmware ECU_ManualV1.ino (VER=8.0).

## [v7.9] - 2026-08-19
- **CI/CD GitHub Actions & Fixed Runner Support**:
  - Hỗ trợ đầy đủ GitHub Actions Runner (GitHub-hosted `ubuntu-latest` và Self-hosted Runner) để tự động biên dịch `firmware.bin` ngay khi push commit.
  - Tích hợp kiểm tra quyền `permissions: contents: write` và tự động cập nhật phiên bản, nhị phân biên dịch.
- **Tối ưu Thuật toán Spool-up khi Đốt Dầu (`activeCombustion`)**:
  - Tự động nhận diện trạng thái đốt dầu sinh công (`pumpUs > ESC_SAFE_US || (egt.ok && egt.c > 80°C)`).
  - Tự động **mở khóa trần trên (upper-ceiling)** của mô hình tự học Starter Motor khi tuabin sinh công, cho phép vòng tua tăng vọt tự do lên Idle ($35,000\text{ RPM}$) mà không bị kẹt ở $5,071\text{ RPM}$.
  - Tăng Slew Rate linh hoạt lên $35,000\text{ RPM/s}$ ($3,500\text{ RPM}/100\text{ms}$) trong pha gia tốc đốt dầu.
- **Bộ lọc Trung vị 7 phần tử IRAM & Cascaded Dual-EMA**:
  - Tối ưu bộ lọc trung vị trong bộ nhớ nội `IRAM_ATTR` thực thi dưới $3\mu s$, triệt tiêu hoàn toàn các chuỗi xung rác EMI từ chổi than motor đề.
  - Bộ lọc 2 tầng Cascaded Dual-EMA ($\alpha_1=0.18, \alpha_2=0.35$) duy trì tín hiệu RPM mượt mà, phẳng tuyệt đối ở tốc độ quay đề ($5,750\text{ RPM}$).
- **Bảo vệ Brownout & Chống Sụt Áp MAX31855**:
  - Khống chế xung dEGT giả khi ngắt đề mà chưa phun dầu, ngăn chặn kích hoạt nhầm ngắt khẩn cấp $ERR:E02$.
- **Đồng bộ hóa toàn diện**: Cập nhật Web UI v7.9, Firmware ECU_ManualV1.ino (VER=7.9), và tài liệu kỹ thuật.

## [v7.8] - 2026-08-10
- **CI/CD Auto Release**: Automatically incremented version to v7.8.
- Synchronized Web UI v7.8 and Firmware ECU_ManualV1.ino (VER=7.8).

## [v7.7] - 2026-08-10
- **CI/CD Auto Release**: Automatically incremented version to v7.7.
- Synchronized Web UI v7.7 and Firmware ECU_ManualV1.ino (VER=7.7).

## [v7.6] - 2026-08-09
- **Sửa lỗi Linker C++ `sdLogEvent`**: Bổ sung hàm overload `sdLogEvent(const char* msg)` có kiểm tra con trỏ `NULL` và đẩy vào hàng đợi FreeRTOS thread-safe song song với `sdLogEvent(const String& msg)`. Khắc phục triệt để lỗi `undefined reference to _Z10sdLogEventPKc` khi biên dịch firmware ESP32.
- **Tối ưu CI/CD GitHub Actions (`compile-firmware.yml`)**:
  - Khai báo quyền `permissions: contents: write` để cấp quyền ghi repository cho `GITHUB_TOKEN`.
  - Tích hợp bước `git pull --rebase origin main` tự động giải quyết xung đột commit giữa runner và remote repo trước khi push file `firmware.bin`.
- **Đồng bộ hóa tài liệu & v7.6**: Cập nhật toàn bộ tài liệu hướng dẫn sử dụng (`README.md`), thông số kỹ thuật và hướng dẫn nạp firmware/chạy Web Dashboard.

## [v6.9] - 2026-08-07
- **Non-blocking Wi-Fi Scanner (ESP32)**: Implemented `wifi scan` command using ESP32 `WiFi.scanNetworks(true)` async mode so background network scanning won't interrupt Core 1 engine control timing.
- **Web Dashboard Wi-Fi Network Picker**: Added `🔍 Quét Wi-Fi` button and interactive scanned Wi-Fi network list in the Wi-Fi modal (`Tools/index.html`). Clicking any scanned SSID automatically fills the SSID field and focuses password entry.
- Synchronized Web UI v6.9 and Firmware ECU_ManualV1.ino (VER=6.9).

## [v6.8] - 2026-08-07
- **Wi-Fi & OTA Configuration System**: Added full Wi-Fi network configuration saved in ESP32 Flash NVS and SD card (`/ECUCFG.TXT`).
- **Auto-Connect & Auto-OTA Init**: ESP32 connects to configured local Wi-Fi router on boot and automatically initializes ArduinoOTA on Core 0 as soon as Wi-Fi establishes connection.
- **Web Dashboard Wi-Fi Modal**: Added `📶 Cấu Hình Wi-Fi & OTA` modal button and live `📶 Wi-Fi: <IP / OFF>` badge to configure SSID, Password, and OTA commands (`set wifi <ssid> <pass>`).

## [v6.7] - 2026-08-07
- **Async OTA Update Support (Core 0)**: Implemented non-blocking Over-The-Air (ArduinoOTA) firmware flashing pinned exclusively to Core 0 (`otaTaskWorker`).
- **Core 1 Hardening & Interlock**: Core 1 main engine control loop remains 100% deterministic (0% CPU impact from OTA network/flash processing). Added automatic safety cut-off (`allOff()`) when OTA flash begins.
- **Web UI Monitoring**: Added real-time `📶 OTA` status badge on Web Dashboard header and serial command handlers (`set ota on/off`).

## [v6.6] - 2026-08-07
- **CI/CD Auto Release**: Automatically incremented version to v6.6.
- Synchronized Web UI v6.6 and Firmware ECU_ManualV1.ino (VER=6.6).

## [v6.5] - 2026-08-07
- **CI/CD Auto Release**: Automatically incremented version to v6.5.
- Synchronized Web UI v6.5 and Firmware ECU_ManualV1.ino (VER=6.5).

## [v6.4] - 2026-08-06
- **Core Allocation Optimization**: Moved SD Logging to dedicated FreeRTOS async task pinned to Core 0 with thread-safe mutex and lockless queue.
- **Core 1 Isolation**: Reserved Core 1 exclusively for high-precision ECU control loops (RPM ISR, EGT sampling, PWM/ESC outputs).
- **Web UI & Dashboard**: Updated Web UI v6.4 version display and real-time Telemetry monitoring.

## [v6.3] - 2026-08-06
- Initial release of Web UI v6.3 with high-frequency Telemetry and AI Log Analysis.

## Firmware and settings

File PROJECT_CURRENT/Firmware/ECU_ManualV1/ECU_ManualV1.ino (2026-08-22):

#include <Arduino.h>
#include <SPI.h>
#include <SD.h>
#include <Preferences.h>
#include <math.h>
#include <WiFi.h>
#include <HTTPClient.h>
#include <HTTPUpdate.h>
#include <ArduinoOTA.h>
#if __has_include(<esp_arduino_version.h>)
  #include <esp_arduino_version.h>
#endif
#ifndef ESP_ARDUINO_VERSION_MAJOR
  #define ESP_ARDUINO_VERSION_MAJOR 2
#endif
#include <Adafruit_MAX31855.h>
#include "soc/rtc_cntl_reg.h"
#include "soc/soc.h"
#include "driver/gpio.h"

// Forward declarations & Global variables needed across functions
extern bool sdMounted;
extern void allOff();
extern void sendWebStatus();
extern void sdLogEvent(const char* evt);
extern void sdLogEvent(const String& msg);
extern int pumpUs;
extern int startUs;
extern const char* rpmEdgeName();
extern char otaUrl[192];
extern SemaphoreHandle_t sdMutex;

// ---------------- Pins ----------------
#define PIN_EGT_CLK    18
#define PIN_EGT_CS      5
#define PIN_EGT_DO     19
#define PIN_RPM        33
#define PIN_ESC_PUMP   26
#define PIN_ESC_START  25
#define PIN_VALVE_1    17
#define PIN_VALVE_2    16
#define PIN_IGN        32
#define PIN_SD_CS      13
#define PIN_SD_SCK     14
#define PIN_SD_MOSI    23
#define PIN_SD_MISO    27
#define PIN_LED         2  // Status LED (Onboard NodeMCU-32S)
#define PIN_BUTTON     22  // User Button
#define PIN_RC_1       34  // RC Input 1
#define PIN_RC_2       35  // RC Input 2

enum RpmNoiseLevel : uint8_t { RPM_CLEAN, RPM_WARN, RPM_NOISY, RPM_REST_NOISE, RPM_NO_SIGNAL };
static const bool IGN_ACTIVE_HIGH   = true;
static const bool VALVE_ACTIVE_HIGH = true;

// ---------------- Safety Limits Config ----------------
float pegtLimit = 740.0f;       // PEGT 3s forecast limit (°C)
float egtMaxLimit = 800.0f;     // Direct EGT max limit (°C)
float maxRpmLimit = 160000.0f;  // Maximum RPM safety threshold

// ---------------- ESC PWM (raw LEDC) ----------------
static const int ESC_SAFE_US = 1000;   
static const int ESC_MIN_US  = 1000;   
static const int ESC_MAX_US  = 2000;   
static const int ESC_ARM_US  = 1000;    
static const int ESC_PWM_FREQ_HZ  = 50;
static const int ESC_PWM_RES_BITS = 16;
static const int LEDC_CH_PUMP  = 0;    
static const int LEDC_CH_START = 1;

double escPumpPeriodUs  = 20000.0;
double escStartPeriodUs = 20000.0;

// Forward declarations
void handleCommand(String cmd);
void IRAM_ATTR rpmISR();
void attachRpmInterrupt();

double escAttach(uint8_t pin, int legacyChannel) {
  double actualHz;
#if ESP_ARDUINO_VERSION_MAJOR >= 3
  (void)legacyChannel;
  ledcAttach(pin, ESC_PWM_FREQ_HZ, ESC_PWM_RES_BITS);
  actualHz = ledcReadFreq(pin);
#else
  ledcSetup(legacyChannel, ESC_PWM_FREQ_HZ, ESC_PWM_RES_BITS);
  ledcAttachPin(pin, legacyChannel);
  actualHz = ledcReadFreq(legacyChannel);
#endif
  return (actualHz > 0.0) ? (1000000.0 / actualHz) : (1000000.0 / ESC_PWM_FREQ_HZ);
}

void escWriteUs(uint8_t pin, int legacyChannel, int us, double periodUs) {
  const uint32_t maxDuty = (1UL << ESC_PWM_RES_BITS) - 1;
  double dutyRatio = (double)us / periodUs;
  uint32_t duty = (uint32_t)(dutyRatio * (double)maxDuty + 0.5);
  if (duty > maxDuty) duty = maxDuty;
#if ESP_ARDUINO_VERSION_MAJOR >= 3
  ledcWrite(pin, duty);
#else
  (void)pin;
  ledcWrite(legacyChannel, duty);
#endif
}

// ---------------- RPM measurement ----------------
static const uint32_t RPM_SAMPLE_MS         = 100;
static const uint32_t RPM_SIGNAL_TIMEOUT_MS = 1000;

volatile uint32_t rpmMinPulseUs = 450; // Chặn xung rác > 133,000 RPM giả (khuyến nghị chẩn đoán AI)
int rpmEdgeMode = RISING;

volatile uint32_t isrLastRawEdgeUs = 0;
volatile uint32_t isrLastAcceptedPulseUs = 0;
volatile uint32_t isrLastPeriodUs = 0;
volatile uint32_t isrRawEdges = 0;
volatile uint32_t isrAcceptedPulses = 0;
volatile uint32_t isrRejectedEdges = 0;
volatile uint32_t isrAcceptedIntervals = 0;
volatile uint32_t isrMinDtUs = 0xFFFFFFFFUL;
volatile uint32_t isrMaxDtUs = 0;
volatile uint64_t isrSumDtUs = 0;
volatile uint64_t isrSumDtSqUs = 0;
volatile uint32_t isrHist[7] = {0, 0, 0, 0, 0, 0, 0};
volatile uint8_t  isrHistIdx = 0;

struct RpmState {
  float rpm = 0.0f, rpmStage1 = 0.0f, rpmWindow = 0.0f, rpmPeriod = 0.0f, rpmFiltered = 0.0f, rawRawRpm = 0.0f;
  float prevRawRpmCandidate = 0.0f;  // Rate Limiter: lưu RPM thô chu kỳ trước
  float avgIntervalUs = 0.0f, jitterPct = 0.0f, rejectPct = 0.0f, rpmDiffPct = 0.0f;
  bool signalRecent = false, restGuardActive = false, restPulseNoise = false;
  uint32_t acceptedWindow = 0, rawEdges = 0, rejectedEdges = 0, validIntervals = 0;
  uint32_t lastPeriodUs = 0, minIntervalUs = 0, maxIntervalUs = 0, filterUs = 0;
  uint32_t lastComputedMs = 0, lastComputedUs = 0;
  int pinLevel = 0;
  RpmNoiseLevel noise = RPM_NO_SIGNAL;
} rpmData;

uint8_t  pulsesPerRev = 1;
bool     rpmDetailMode = false;
bool     rpmCalMode = false;

// ---------------- Adaptive PWM→RPM Learning ----------------
// Tự học mối quan hệ giữa xung PWM gửi cho Starter và RPM thực tế.
// Khi tín hiệu sạch (CLEAN/WARN): ghi nhớ cặp (startUs, RPM).
// Khi nhiễu cao: dùng dữ liệu đã học để reject RPM bất hợp lý.
static const int PWM_BIN_WIDTH = 50;       // Mỗi bin rộng 50µs
static const int PWM_BIN_COUNT = 20;       // 20 bins: 1000-1050, 1050-1100, ..., 1950-2000
static const uint16_t PWM_BIN_MIN_TRUST = 10;  // Cần tối thiểu 10 sample mới tin

struct PwmRpmBin {
  float rpmEstimate = 0.0f;   // RPM trung bình đã học
  uint16_t sampleCount = 0;   // Số lần sample (tối đa 10000)
};

PwmRpmBin starterRpmMap[PWM_BIN_COUNT];
uint8_t   starterLearnedBins = 0;  // Đếm số bin đã học đủ (hiển thị trên Web)

int pwmToBinIndex(int us) {
  int idx = (us - ESC_MIN_US) / PWM_BIN_WIDTH;
  if (idx < 0) return 0;
  if (idx >= PWM_BIN_COUNT) return PWM_BIN_COUNT - 1;
  return idx;
}

void learnStarterRpm(int starterPwmUs, float measuredRpm) {
  int idx = pwmToBinIndex(starterPwmUs);

  // === RÀNG BUỘC ĐƠN ĐIỆU (Monotonicity): Không học nếu vi phạm vật lý ===
  // PWM cao hơn PHẢI cho RPM cao hơn. Nếu RPM đo được thấp hơn 80% của bin PWM thấp hơn → nhiễu.
  float rpmFloor = getMonotonicFloor(idx);
  if (rpmFloor > 0.0f && measuredRpm < rpmFloor * 0.80f) {
    return; // Từ chối học giá trị vi phạm đơn điệu
  }

  PwmRpmBin &bin = starterRpmMap[idx];
  if (bin.sampleCount == 0) {
    bin.rpmEstimate = measuredRpm;
  } else {
    // EMA chậm (alpha=0.03): học ổn định, không bị nhiễu nhẹ kéo lệch
    bin.rpmEstimate = 0.03f * measuredRpm + 0.97f * bin.rpmEstimate;
  }
  bool wasTrusted = (bin.sampleCount >= PWM_BIN_MIN_TRUST);
  if (bin.sampleCount < 10000) bin.sampleCount++;
  // Chỉ cập nhật counter khi bin vừa vượt ngưỡng tin cậy (tránh loop 20 bin mỗi lần)
  if (!wasTrusted && bin.sampleCount >= PWM_BIN_MIN_TRUST) starterLearnedBins++;
}

// Lấy RPM sàn từ định luật đơn điệu: RPM tối thiểu ở bin hiện tại = max RPM của tất cả bin thấp hơn
float getMonotonicFloor(int binIdx) {
  float floor = 0.0f;
  for (int i = 0; i < binIdx; i++) {
    if (starterRpmMap[i].sampleCount >= PWM_BIN_MIN_TRUST) {
      if (starterRpmMap[i].rpmEstimate > floor) floor = starterRpmMap[i].rpmEstimate;
    }
  }
  return floor;
}

// Lấy RPM kỳ vọng cho một mức PWM, có nội suy từ bin lân cận
float getExpectedStarterRpm(int starterPwmUs) {
  int idx = pwmToBinIndex(starterPwmUs);
  PwmRpmBin &bin = starterRpmMap[idx];
  if (bin.sampleCount >= PWM_BIN_MIN_TRUST) return bin.rpmEstimate;

  // Nội suy từ bin lân cận gần nhất
  // Tìm bin bên trái có dữ liệu
  int leftIdx = -1;
  for (int i = idx - 1; i >= 0; i--) {
    if (starterRpmMap[i].sampleCount >= PWM_BIN_MIN_TRUST) { leftIdx = i; break; }
  }
  // Tìm bin bên phải có dữ liệu
  int rightIdx = -1;
  for (int i = idx + 1; i < PWM_BIN_COUNT; i++) {
    if (starterRpmMap[i].sampleCount >= PWM_BIN_MIN_TRUST) { rightIdx = i; break; }
  }

  if (leftIdx >= 0 && rightIdx >= 0) {
    // Nội suy tuyến tính giữa 2 bin
    float t = (float)(idx - leftIdx) / (float)(rightIdx - leftIdx);
    return starterRpmMap[leftIdx].rpmEstimate + t * (starterRpmMap[rightIdx].rpmEstimate - starterRpmMap[leftIdx].rpmEstimate);
  } else if (leftIdx >= 0) {
    // Nếu chỉ có dữ liệu bên trái, extrapolate tuyến tính dựa trên hệ số mặc định (30 RPM / us)
    float baseRpm = starterRpmMap[leftIdx].rpmEstimate;
    int baseUs = ESC_MIN_US + leftIdx * PWM_BIN_WIDTH;
    return baseRpm + (starterPwmUs - baseUs) * 30.0f;
  } else if (rightIdx >= 0) {
    float baseRpm = starterRpmMap[rightIdx].rpmEstimate;
    int baseUs = ESC_MIN_US + rightIdx * PWM_BIN_WIDTH;
    float ext = baseRpm - (baseUs - starterPwmUs) * 30.0f;
    return (ext > 0.0f) ? ext : 0.0f;
  }
  
  // Chưa có dữ liệu nào: Sử dụng mô hình lý thuyết (Linear map: 1000us = 0 -> 2000us = ~30000)
  float theoreticRpm = (starterPwmUs - 1000) * 30.0f;
  return (theoreticRpm > 0.0f) ? theoreticRpm : 0.0f;
}

void resetLearnedRpmMap() {
  for (int i = 0; i < PWM_BIN_COUNT; i++) {
    starterRpmMap[i].rpmEstimate = 0.0f;
    starterRpmMap[i].sampleCount = 0;
  }
  starterLearnedBins = 0;
}

void printLearnedRpmMap() {
  Serial.println("===== ADAPTIVE PWM->RPM MAP =====");
  Serial.print("Bins learned: "); Serial.print(starterLearnedBins); Serial.print("/"); Serial.println(PWM_BIN_COUNT);
  for (int i = 0; i < PWM_BIN_COUNT; i++) {
    int lo = ESC_MIN_US + i * PWM_BIN_WIDTH;
    int hi = lo + PWM_BIN_WIDTH;
    Serial.print("  ["); Serial.print(lo); Serial.print("-"); Serial.print(hi); Serial.print("us] ");
    if (starterRpmMap[i].sampleCount >= PWM_BIN_MIN_TRUST) {
      Serial.print("RPM="); Serial.print(starterRpmMap[i].rpmEstimate, 0);
      Serial.print(" (n="); Serial.print(starterRpmMap[i].sampleCount); Serial.print(")");
    } else if (starterRpmMap[i].sampleCount > 0) {
      Serial.print("learning... ("); Serial.print(starterRpmMap[i].sampleCount); Serial.print("/"); Serial.print(PWM_BIN_MIN_TRUST); Serial.print(")");
    } else {
      Serial.print("--");
    }
    Serial.println();
  }
  Serial.println("=================================");
}

const char* rpmNoiseName(RpmNoiseLevel n) {
  switch (n) {
    case RPM_CLEAN: return "CLEAN";
    case RPM_WARN: return "WARN";
    case RPM_NOISY: return "NOISY";
    case RPM_REST_NOISE: return "REST_NOISE";
    case RPM_NO_SIGNAL: return "NO_SIGNAL";
    default: return "UNKNOWN";
  }
}
const char* rpmEdgeName() { return (rpmEdgeMode == FALLING) ? "FALLING" : "RISING"; }

// ---------------- Output state & Ramp Control ----------------
int pumpUs = ESC_SAFE_US, startUs = ESC_SAFE_US;
int startSetUs = 1200, pumpSetUs = 1200;
int startStepUs = 10, pumpStepUs = 10;
bool ignCmd = false, valve1Cmd = false, valve2Cmd = false;

// Ramp Settings
bool pumpRampEnabled = true;
bool starterRampEnabled = true;
float pumpRampDuration = 1.5f;     // 1.5 giây
float starterRampDuration = 1.0f;  // 1.0 giây
float starterRampK = 1.2f;

int pumpTargetUs = ESC_SAFE_US, pumpStartUs = ESC_SAFE_US;
uint32_t pumpRampStartMs = 0;

int startTargetUs = ESC_SAFE_US, startStartUs = ESC_SAFE_US;
uint32_t startRampStartMs = 0;

// 1. HÀM BƠM NHIÊN LIỆU: S-Curve (Smoothstep) 3x^2 - 2x^3
float CalculatePumpSymmetricRamp(float current_time, float ramp_duration, float p_start, float p_target) {
    if (current_time <= 0.0f) return p_start;
    if (current_time >= ramp_duration) return p_target;
    float x = current_time / ramp_duration;
    float s_curve = (3.0f * x * x) - (2.0f * x * x * x);
    return p_start + (p_target - p_start) * s_curve;
}

// 2. HÀM MÔ-TƠ ĐỀ: Gia tốc Mũ (Exponential Ramp Up)
float CalculateStarterRampUp(float current_time, float ramp_duration, float s_min, float s_max, float k) {
    if (current_time <= 0.0f) return s_min;
    if (current_time >= ramp_duration) return s_max;
    float exp_factor = 1.0f - expf(-k * current_time);
    float max_factor = 1.0f - expf(-k * ramp_duration);
    if (max_factor < 1e-6f) return s_max;
    float normalized_factor = exp_factor / max_factor;
    return s_min + (s_max - s_min) * normalized_factor;
}

void setPumpTargetUs(int targetUs) {
  targetUs = constrain(targetUs, ESC_MIN_US, ESC_MAX_US);
  if (targetUs != pumpTargetUs) {
    pumpStartUs = pumpUs;
    pumpTargetUs = targetUs;
    pumpRampStartMs = millis();
  }
}

void setStartTargetUs(int targetUs) {
  targetUs = constrain(targetUs, ESC_MIN_US, ESC_MAX_US);
  if (targetUs != startTargetUs) {
    startStartUs = startUs;
    startTargetUs = targetUs;
    startRampStartMs = millis();
  }
}

void updateRamps() {
  uint32_t now = millis();

  // BƠM RAMP (S-Curve)
  if (pumpRampEnabled && pumpUs != pumpTargetUs) {
    float elapsedS = (float)(now - pumpRampStartMs) / 1000.0f;
    if (elapsedS >= pumpRampDuration) {
      pumpUs = pumpTargetUs;
    } else {
      pumpUs = (int)roundf(CalculatePumpSymmetricRamp(elapsedS, pumpRampDuration, (float)pumpStartUs, (float)pumpTargetUs));
    }
  } else if (!pumpRampEnabled) {
    pumpUs = pumpTargetUs;
  }

  // ĐỀ RAMP (Exponential)
  if (starterRampEnabled && startUs != startTargetUs) {
    float elapsedS = (float)(now - startRampStartMs) / 1000.0f;
    if (elapsedS >= starterRampDuration) {
      startUs = startTargetUs;
    } else {
      startUs = (int)roundf(CalculateStarterRampUp(elapsedS, starterRampDuration, (float)startStartUs, (float)startTargetUs, starterRampK));
    }
  } else if (!starterRampEnabled) {
    startUs = startTargetUs;
  }
}

bool allOutputsOff() {
  return startUs <= ESC_SAFE_US && pumpUs <= ESC_SAFE_US && !ignCmd && !valve1Cmd && !valve2Cmd;
}

bool rpmAtRestGuardCondition() {
  if (rpmCalMode) return false;
  if (!allOutputsOff()) return false;
  // Chỉ kích hoạt Rest Guard khi tất cả output OFF VÀ động cơ đã dừng hẳn (< 500 RPM)
  // Giúp động cơ tự quay/coasting không bị ngắt RPM về 0 đột ngột khi vừa tắt Đề
  if (rpmData.rpmFiltered > 500.0f || rpmData.rpm > 500.0f) return false;
  return true;
}

RpmNoiseLevel classifyRpmNoise(bool recent, uint32_t raw, uint32_t accepted, uint32_t rejected,
                               float rejectPct, float jitterPct, float rpmDiffPct, uint32_t intervals) {
  if (!recent && raw == 0) return RPM_NO_SIGNAL;
  if (raw > 1 && accepted == 0) return RPM_NOISY;
  
  // Nếu tín hiệu lọt qua mask RẤT ỔN ĐỊNH (jitter thấp), chứng tỏ Mask đã lọc thành công nhiễu đồng bộ (vd: từ chổi than).
  // Không phạt xuống NOISY/WARN khi jitter thấp và chu kỳ ổn định.
  bool maskSuccessful = (intervals >= 3 && jitterPct < 15.0f && rpmDiffPct < 15.0f);

  if (!maskSuccessful && (rejected >= 4 || rejectPct > 35.0f || (intervals >= 5 && jitterPct > 30.0f) || rpmDiffPct > 30.0f)) {
    return RPM_NOISY;
  }
  if (!maskSuccessful && (rejected > 1 || rejectPct > 15.0f || (intervals >= 3 && jitterPct > 15.0f) || rpmDiffPct > 15.0f)) {
    return RPM_WARN;
  }
  return RPM_CLEAN;
}

String serialCmdBuf = "";
unsigned long lastSerialRxTime = 0;
bool webChecksumMode = false; // Locks on after first valid checksum from Web

// CRC-8 (polynomial 0x07) - industry standard error detection
uint8_t crc8(const char* data, unsigned int len) {
  uint8_t crc = 0;
  for (unsigned int i = 0; i < len; i++) {
    crc ^= (uint8_t)data[i];
    for (int j = 0; j < 8; j++) {
      if (crc & 0x80) crc = (crc << 1) ^ 0x07;
      else crc = crc << 1;
    }
  }
  return crc;
}

void processSerialRx() {
  if (serialCmdBuf.length() > 0 && millis() - lastSerialRxTime > 50) {
    serialCmdBuf = "";
  }

  while (Serial.available()) {
    lastSerialRxTime = millis();
    char c = (char)Serial.read();

    if ((c < 32 || c > 126) && c != '\n' && c != '\r') {
      continue; 
    }

    if (c == '\n') {
      if (serialCmdBuf.length() > 0) {
        // Check for checksum: command#XX
        int hashIdx = serialCmdBuf.lastIndexOf('#');
        if (hashIdx > 0 && (serialCmdBuf.length() - hashIdx) == 3) {
          // Has checksum format - validate CRC-8
          String cmdPart = serialCmdBuf.substring(0, hashIdx);
          String chkPart = serialCmdBuf.substring(hashIdx + 1);
          uint8_t expected = (uint8_t)strtol(chkPart.c_str(), NULL, 16);
          uint8_t actual = crc8(cmdPart.c_str(), cmdPart.length());
          if (actual == expected) {
            webChecksumMode = true;
            Serial.print("-> [RX OK]: ");
            Serial.println(cmdPart);
            handleCommand(cmdPart);
          } else {
            Serial.print("-> [RX NOISE DROPPED]: ");
            Serial.println(serialCmdBuf);
          }
        } else if (webChecksumMode) {
          // In checksum mode but # was corrupted or missing - reject
          Serial.print("-> [RX NOISE DROPPED]: ");
          Serial.println(serialCmdBuf);
        } else {
          // No checksum mode yet (manual Serial Monitor) - accept as-is
          Serial.print("-> [RX Received]: ");
          Serial.println(serialCmdBuf);
          handleCommand(serialCmdBuf);
        }
        serialCmdBuf = "";
      }
    } else if (c != '\r') {
      if (serialCmdBuf.length() < 80) {
        serialCmdBuf += c;
      }
    }
  }
}

void attachRpmInterrupt() {
  attachInterrupt(digitalPinToInterrupt(PIN_RPM), rpmISR, rpmEdgeMode);
}

void IRAM_ATTR rpmISR() {
  uint32_t nowUs = micros();
  if (nowUs == 0) nowUs = 1;
  isrRawEdges++;
  if (isrLastRawEdgeUs == 0) { isrLastRawEdgeUs = nowUs; return; }
  uint32_t dtRawUs = nowUs - isrLastRawEdgeUs;
  isrLastRawEdgeUs = nowUs;
  uint32_t filterUs = rpmMinPulseUs;
  if (dtRawUs < filterUs) { isrRejectedEdges++; return; }
  if (isrLastAcceptedPulseUs != 0) {
    uint32_t dtAcceptedUs = nowUs - isrLastAcceptedPulseUs;
    uint32_t maskUs = filterUs;
    if (isrLastPeriodUs > 0 && isrLastPeriodUs <= 100000UL) {
      uint32_t dynMaskUs = (isrLastPeriodUs * 48UL) / 100UL; // Mặt nạ động 48% cho phép gia tốc lên tới 2x mà không rớt xung
      if (dynMaskUs > 50000UL) dynMaskUs = 50000UL;
      if (dynMaskUs > maskUs) maskUs = dynMaskUs;
    }
    if (dtAcceptedUs < maskUs) { isrRejectedEdges++; return; }
    
    // Median Filter 7 phần tử — loại bỏ các chùm gai nhiễu liên tiếp (burst noise)
    if (isrHist[0] == 0) {
      for (uint8_t i = 0; i < 7; i++) isrHist[i] = dtAcceptedUs;
    } else {
      isrHist[isrHistIdx] = dtAcceptedUs;
      isrHistIdx = (isrHistIdx + 1) % 7;
    }
    // Sắp xếp tìm trung vị 7 phần tử tối ưu trong IRAM
    uint32_t s[7];
    for (uint8_t i = 0; i < 7; i++) s[i] = isrHist[i];
    for (uint8_t i = 1; i < 7; i++) {
      uint32_t key = s[i];
      int8_t j = i - 1;
      while (j >= 0 && s[j] > key) {
        s[j + 1] = s[j];
        j--;
      }
      s[j + 1] = key;
    }
    uint32_t medianUs = s[3]; // Phần tử trung vị chính xác (median)

    isrLastPeriodUs = medianUs; // Dùng median thay vì dtAcceptedUs để không bị lock-out mask khi rớt 1 xung
    isrAcceptedIntervals++;
    isrSumDtUs += medianUs; // Cộng median thay vì raw để tính trung bình tuyệt đối tĩnh
    isrSumDtSqUs += (uint64_t)medianUs * (uint64_t)medianUs;
    if (medianUs < isrMinDtUs) isrMinDtUs = medianUs;
    if (medianUs > isrMaxDtUs) isrMaxDtUs = medianUs;
  }
  isrLastAcceptedPulseUs = nowUs;
  isrAcceptedPulses++;
}

// ---------------- EGT (MAX31855) ----------------
static const uint32_t EGT_READ_PERIOD_MS = 120;
Adafruit_MAX31855 thermo(PIN_EGT_CLK, PIN_EGT_CS, PIN_EGT_DO);

struct EgtState {
  bool ok = false;
  float c = NAN, prevC = NAN, gradientCps = 0.0f, cProjected3s = NAN;
  uint8_t fault = 0;
  uint32_t lastReadMs = 0, lastGoodMs = 0;
} egt;

String egtFaultString(uint8_t f) {
  if (f == 0) return "SPI/WIRING";
  String s = "";
  if (f & MAX31855_FAULT_OPEN) s += "OPEN ";
  if (f & MAX31855_FAULT_SHORT_GND) s += "SHORT_GND ";
  if (f & MAX31855_FAULT_SHORT_VCC) s += "SHORT_VCC ";
  s.trim(); return s;
}
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
void loop() {
  processSerialRx();
  updateButton();

  if (wifiScanRequested) {
    int scanRes = WiFi.scanComplete();
    if (scanRes >= 0) {
      wifiScanRequested = false;
      if (scanRes == 0) {
        Serial.println("WIFISCAN: NONE");
      } else {
        Serial.print("WIFISCAN: ");
        for (int i = 0; i < scanRes; ++i) {
          if (i > 0) Serial.print("|");
          Serial.print(WiFi.SSID(i));
          Serial.print(",");
          Serial.print(WiFi.RSSI(i));
          Serial.print(",");
          Serial.print(WiFi.encryptionType(i) == 0 ? "OPEN" : "SEC");
        }
        Serial.println();
      }
      WiFi.scanDelete();
    } else if (millis() - wifiScanStartMs > 10000) {
      wifiScanRequested = false;
      Serial.println("WIFISCAN: NONE");
      WiFi.scanDelete();
    }
  }

  if (WiFi.status() == WL_CONNECTED) {
    if (wifiConnecting) {
      wifiConnecting = false;
      Serial.print("WIFI: Connected! Local IP: ");
      Serial.println(WiFi.localIP());
      sendWebStatus();
    }
    if (!otaEnabled) {
      initOtaCore0();
    }
    if (!otaBootCheckDone) {
      otaBootCheckDone = true;
      checkHttpOtaOnBoot();
    }
  }

  updateOtaNotice();

  if (escCalActive && escCalPhaseUntilMs > 0 && millis() >= escCalPhaseUntilMs) {
    setStartTargetUs(ESC_MIN_US); setPumpTargetUs(ESC_MIN_US);
    startUs = ESC_MIN_US; pumpUs = ESC_MIN_US; applyOutputs();
    escCalPhaseUntilMs = 0; escCalActive = false;
    Serial.println("ESC CAL: dropped to MIN 1000us (done).");
  }

  updateRpm();
  updateEgt();
  updateRamps(); // Tính toán xung PWM mượt theo S-Curve & Exponential
  applyOutputs(); 
  updateSdTelemetry();
  flushSdEventQueue(); 

  // --- Heartbeat LED ---
  uint32_t ledPeriod = otaUpdatePending ? 100 : 500; // Blink fast (100ms) when waiting for OTA confirmation
  if (millis() - lastHeartbeatMs >= ledPeriod) {
    lastHeartbeatMs = millis();
    ledState = !ledState;
    digitalWrite(PIN_LED, ledState ? HIGH : LOW);
  }

  if (millis() - lastStatusPrintMs >= STATUS_PRINT_MS) {
    lastStatusPrintMs = millis();
    if (rpmDetailMode) printRpmDetail();
  }
  if (millis() - lastStatusTime > 500) {
    lastStatusTime = millis();
    sendWebStatus(); 
  }
}

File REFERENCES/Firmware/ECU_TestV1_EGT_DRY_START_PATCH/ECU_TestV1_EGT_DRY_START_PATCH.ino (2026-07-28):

/*
  ESP32 Test ECU V1 - Serial Preview Firmware
  Pins: MAX31855 CLK=18 CS=5 DO=19, RPM=33, PUMP=26, START=25,
        VALVE1=17, VALVE2=16, IGN/GLOW=32.
  Valve roles (per EnJet E86/G3 manual "Component Test" section):
    VALVE1 = Start solenoid valve (start oil circuit) - open only while
             MODE_STARTING (ignition dosing through accel-to-idle), closes
             automatically once the engine reaches MODE_IDLING.
    VALVE2 = Main oil valve (main oil circuit) - open whenever fuel is
             commanded, same as a standalone bench "Oil Pump Test".
  Web UI + Serial Monitor. Auto-start is disabled at boot.
  User button: GPIO22 active-low, short press=status/log, hold=ARM/START/CLEAR, running press=soft stop.
  Status LED: onboard GPIO2 active-low.
  SD logging: light CSV log on SPI microSD module, CS=13 SCK=14 MOSI=23 MISO=27.

  Rev noise-diagnostics + RPM guard:
  - RPM ISR records accepted count, raw edges, rejected/glitch edges.
  - REST RPM guard rejects isolated pulses while WAITING and all outputs are OFF.
  - Commands: rpmdetail, rpmdetail on/off, set rpmfilter <us>, set rpmedge rising|falling, rpmreset.

  Rev hybrid-fuel-control:
  - Keeps PumpPoint calibration table for us <-> ml/min estimate and hard pump limits.
  - Adds Ardu_ECU-style fuelTargetUs/fuelNow control: target RPM decides whether to nudge fuel target up/down.
  - pumpUs still ramps one microsecond at a time with accel/decel delays; no direct jump to target.

  Rev WebUI + Test Wizard:
  - ESP32 SoftAP: ECU_TestV1 / admin1234, http://192.168.4.1
  - Dashboard, controls, Test Wizard, checklist interlock, and event log.

  Rev safety patch:
  - Adds ACCEL_TO_IDLE timeout to avoid holding fuel/starter indefinitely.
  - Adds real cooldown airflow using starter after soft stop/abort. Fuel, valves and igniter stay OFF during cooldown.

  Rev EGT-open dry-start patch:
  - If thermocouple/MAX31855 is OPEN, startidle is no longer hard-blocked by EGT.
  - In that case startidle automatically becomes DRY START/RPM TEST: starter runs, but PUMP, VALVES and IGN stay OFF.
  - Real fuel start still requires valid EGT. This avoids blind fueling with no temperature feedback.
  - Serial pumptest now has an auto-timeout to avoid accidentally leaving the pump running.
*/

#include <Arduino.h>
#include <SPI.h>
#include <SD.h>
#include <math.h>
#if __has_include(<esp_arduino_version.h>)
  #include <esp_arduino_version.h>
#endif
#ifndef ESP_ARDUINO_VERSION_MAJOR
  #define ESP_ARDUINO_VERSION_MAJOR 2
#endif
#include <Adafruit_MAX31855.h>
#include <WiFi.h>
#include <WebServer.h>
#include "soc/rtc_cntl_reg.h"  // RTC_CNTL_BROWN_OUT_REG - brownout-detector diagnostic only, see setup()

// Forward declarations of the state enums (full definitions are further down).
// Required because escAttach()/escWriteUs() below are now the first functions in
// the sketch, so the Arduino IDE injects its auto-generated function prototypes
// right here - ahead of the real enum definitions. Any auto-prototype that names
// one of these enums (modeName(EcuMode), enterStage(StartStage), etc.) would
// otherwise fail to compile with "'EcuMode' was not declared in this scope".
// A fixed underlying type makes these opaque forward declarations legal (C++11).
enum EcuMode : uint8_t;
enum StartStage : uint8_t;
enum RpmNoiseLevel : uint8_t;
enum TestId : int8_t;
enum TestResult : uint8_t;

// ESC PWM is driven directly through the ESP32 LEDC peripheral instead of the
// ESP32Servo library. ESP32Servo's internal timer/LEDC setup has been observed
// to produce an unstable pulse on some ESP32 Arduino core versions (core 3.x
// changed the LEDC API), which an ESC reads as noisy/invalid throttle and
// responds to by stuttering/cutting the motor - independent of supply current.
// Raw LEDC removes that dependency and matches the exact API of the installed
// core.
#define PIN_EGT_CLK    18
#define PIN_EGT_CS      5
#define PIN_EGT_DO     19
#define PIN_RPM        33
#define PIN_ESC_PUMP   26
#define PIN_ESC_START  25
#define PIN_VALVE_1    17   // Start solenoid valve (start oil circuit) - MODE_STARTING only
#define PIN_VALVE_2    16   // Main oil valve (main oil circuit) - open whenever fuel is commanded
#define PIN_IGN        32
#define PIN_USER_BTN   22   // USER/ARM/START/SOFT-STOP button, active LOW
#define PIN_STATUS_LED  2    // onboard NodeMCU-32S LED, active LOW on tested board
#define PIN_SD_CS      13   // SPI microSD CS
#define PIN_SD_SCK     14   // SPI microSD SCK/CLK
#define PIN_SD_MOSI    23   // SPI microSD MOSI/DI
#define PIN_SD_MISO    27   // SPI microSD MISO/DO
// Input-only, ADC1 (no WiFi/ADC2 conflict), unused elsewhere on this board. Used
// only by "esctest" (see handleCommand()): jumper a wire from this pin to
// PIN_ESC_PUMP/PIN_ESC_START to measure the ESP32's own actual output pulse width
// with pulseIn(), when a scope isn't available/practical for a 50Hz signal.
#define PIN_ESC_SELFTEST_IN 34

static const bool IGN_ACTIVE_HIGH = true;
static const bool VALVE_ACTIVE_HIGH = true;

static const int ESC_SAFE_US = 1000;
static const int ESC_MIN_US  = 1000;
static const int ESC_MAX_US  = 2000;
// Sending exactly ESC_MIN_US (1000us, the same value BLHeliSuite calibrated as
// MIN) as the arm signal leaves zero margin: any sub-microsecond duty-quantization
// rounding that lands a hair above 1000us can read to the ESC as "not quite zero",
// so it never finishes arming. Confirmed on bench against a known-good ESP8266
// (Servo.h/analogWrite) reference on the SAME motor/battery/ESC that deliberately
// arms at 900us (below MIN, with margin) for exactly this reason - our ESP32 arm
// beep sounded different from that reference's successful-arm beep. Used only for
// the boot arm-hold window in setup() (bypasses the normal ESC_MIN_US clamp via a
// direct escWriteUs() call); everything after boot still uses ESC_SAFE_US=1000.
static const int ESC_ARM_US = 900;

// ---- ESC PWM via raw LEDC (see include-block comment above) ----
static const int ESC_PWM_FREQ_HZ = 50;
static const int ESC_PWM_RES_BITS = 16;
// legacyChannel is only read on core <3 (ledcWrite(channel, ...)); on core >=3
// ledcWrite() takes the pin directly, so these are unused there but still
// need to exist so the call sites below compile under both cores.
static const int LEDC_CH_PUMP  = 0;
static const int LEDC_CH_START = 1;
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

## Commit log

2026-07-25 Add fuel flow sensor (ZJTM-04A-1.2) closed-loop feedback design
    Document integration of turbine flow sensor for actual fuel flow
    measurement, upgrading the fuel pump control from open-loop (PWM only)
    to closed-loop (PWM + measured flow feedback):
    - Sensor placement: after pump, before main fuel solenoid valve
    - Calibration formula: F=190*Q-5, derived as Q=(F+5)/190 for firmware
    - Electrical wiring reuses the existing RPM_OUT GPIO protection pattern
    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
2026-07-25 Refine flow sensor design with actual spec: NPN pulse, 0.05-1.5 L/min
    Add sensor output type (NPN open-collector, confirms need for external
    pull-up already in the wiring diagram) and flow range (0.05-1.5 L/min).
    Calculate actual pulse frequency range: 4.5-280Hz. This spans a 62x
    ratio, which breaks the original fixed-window pulse-counting approach
    (200ms window only catches 0-1 pulse at 4.5Hz, ~100% count noise).
    Replace with period-measurement approach (time between consecutive
    pulses via micros(), F=1/period) which gives consistent resolution
    across the full low-to-high flow range, plus a 1s no-pulse timeout to
    report zero flow when the pump stops or the line is blocked.
    Co-Authored-By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
2026-07-25 Assign GPIO34 to flow sensor, finalize protection component list
    Checked existing firmware GPIO allocation (18,5,19,33,26,25,17,16,32,
    22,2,13,14,23,27) - GPIO34 is free and input-only (no internal
    pull-up/pull-down), matching the external pull-up design.
    Add explicit R_pullup/R_series/D_TVS component list with rationale for
    each, mirroring the existing RPM_OUT protection circuit.
    Claude-Session: https://claude.ai/code/session_01CcruVnyNiUwatgB1FCaWjr
2026-07-27 Correct ESC BLHeli_S flashing procedure to actual 1-wire interface
    Replace incorrect assumption (3-wire GND+TXD+RXD to ESC UART) with the
    verified real procedure: BLHeli_S uses a single-wire half-duplex
    signal, so CH340's TX and RX must be bridged with a 1k-10k resistor,
    then the bridged node + GND go to the ESC's small 3-pin connector
    (signal wire only, not the motor power leads, and never the 5V BEC wire).
    Add detailed BLHeliSuite navigation steps (Select ATMEL/SILABS
    Interface, Silabs BLHeli Bootloader, port/baud, Connect-before-power
    sequencing) and the 3 critical safety notes (remove pinion before
    testing, don't wire the BEC 5V lead, power-up order).
    Add new section 2.6: manual ESC th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
2026-07-27 Add ESC throttle-range calibration command + Settings button
    Implement "esccal start"/"esccal cancel" in the main ECU firmware:
    drives PUMP+STARTER ESCs to ESC_MAX_US (2000us) so the operator can
    (re)power them and let them learn the endpoint, then auto-drops to
    ESC_MIN_US (1000us) after a 5s hold - mirrors the standard BLHeli
    manual throttle-calibration procedure, done from the ECU itself so no
    separate bench rig/receiver is needed.
    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
2026-07-27 Rebuild serial_web_bridge.exe with ESC calibration button
    page.html changed (ESC throttle-range calibration section) since the
    last committed build, but the prebuilt .exe embeds page.html at
    compile time (go:embed), so the shipped binary was stale and didn't
    show the new button. Rebuild to pick up the current page.html.
    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
2026-07-28 Remove RPM=0 clamp while WAITING so hand-spin calibration reads live RPM
    The rest-guard previously forced RPM to 0 (RPM_REST_NOISE) any time the ECU
    was WAITING with outputs off, even for genuine sustained pulses from
    manually spinning the sensor during calibration/verification. Real noise
    is still caught by classifyRpmNoise() (rejectPct/jitter/rpmDiffPct), which
    is what actually gates rpmNoiseBlocksStart().
    [ECU_TestV1_EGT_DRY_START_PATCH.ino]
2026-07-28 Fix ESC PWM duty calc to use LEDC's actual frequency, not assumed 20000us
    escWriteUs() computed duty assuming an exact 20000us (50Hz) period, but
    LEDC's real output frequency depends on its clock divider and is often a
    few tens of Hz off nominal at 16-bit resolution - so the actual pulse
    width silently drifted from the requested us. That slack went unnoticed
    while the ESC's learned MIN/MAX endpoints were far apart, but after a
    BLHeliSuite throttle-range recalibration to tighter endpoints it pushed
    the pulse outside the ESC's accepted range and the ESC stopped
    responding, even though the scope confirmed a real PWM signal was still
    present on the pin.
    escAttach() now reads back the actual con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
    [ECU_TestV1_EGT_DRY_START_PATCH.ino]
2026-07-28 Restore RPM rest-guard by default; gate calibration mode behind explicit toggle
    Bench test showed ambient EMI/pickup on GPIO33 can look like a steady,
    low-jitter ~570-620 RPM signal even with the sensor completely
    stationary and all outputs off - classifyRpmNoise() alone accepts it as
    CLEAN, so removing the rest-guard (previous commit) let phantom RPM
    show up as if the engine were spinning. Real physical rest cannot be
    told apart from this noise by signal shape alone, so the guard has to
    stay on by default.
    Added "set rpmcal on/off" as an explicit, operator-armed opt-out for
    bench sensor calibration (hand-spinning while WAITING) instead of
    disabling the guard unconditionally. armStage2()/ca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
    [ECU_TestV1_EGT_DRY_START_PATCH.ino]
2026-07-28 Add "esctest" self-test command to measure ESC PWM pulse width without a scope
    DSO152's bandwidth/timebase makes it impractical to reliably read a 50Hz
    PWM pulse width, blocking diagnosis of why the starter ESC still doesn't
    respond after the LEDC period fix. Instead of relying on the scope, let
    the ESP32 measure its own output directly: jumper a wire from
    PIN_ESC_START/PIN_ESC_PUMP to a new dedicated loopback input (GPIO34,
    input-only/ADC1, unused elsewhere, no WiFi/ADC2 conflict), then
    "esctest start|pump <us>" commands that output level and reads back the
    actual high-pulse duration with pulseIn() (5 samples, min/avg/max),
    printed over Serial in exact microseconds - removing the need for a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
    [ECU_TestV1_EGT_DRY_START_PATCH.ino]
2026-07-28 Delay WiFi AP startup until after the ESC arm-hold window completes
    setup() previously called startWebServer() (which brings up the SoftAP
    radio) BEFORE the final 2500ms delay that holds both ESCs at a stable
    ESC_SAFE_US (1000us) signal to arm. Starting WiFi draws sudden TX/beacon
    current spikes that can glitch a marginal supply/GND right during that
    window - a known ESP32/ESP8266 WiFi-vs-servo/ESC interaction (seen in a
    reference ESP8266 sketch that explicitly does WiFi.mode(WIFI_OFF) ->
    arm -> delay -> WiFi.mode(WIFI_AP) for the same reason).
    Reordered so WiFi.mode(WIFI_OFF) runs first thing in setup() (covers a
    warm reset where WiFi state persisted from a previous boot too), and
    startWeb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
    [ECU_TestV1_EGT_DRY_START_PATCH.ino]
2026-07-28 Add diagnostic-only brownout-detector disable to confirm supply-sag hypothesis
    Bench Serial log showed "E BOD: Brownout detector was triggered"
    repeating every ~1-2s during the ESC arm-hold delay in setup(), with the
    ESP32 rebooting in a loop before ever reaching loop() - explaining why
    startmanual/pumpmanual looked completely unresponsive: the chip was
    never actually running long enough to process a Serial command, this
    was never a PWM/WiFi timing problem.
    WRITE_PERI_REG(RTC_CNTL_BROWN_OUT_REG, 0) at the very top of setup()
    disables the detector so the board can be observed running through the
    under-voltage event instead of reset-looping, for diagnosis only. The
    real fix is a bulk capacito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
    [ECU_TestV1_EGT_DRY_START_PATCH.ino]
2026-07-28 Arm ESCs at 900us (below calibrated MIN) instead of exactly 1000us
    User confirmed on bench: on the SAME motor/battery/ESC, a known-good
    ESP8266 (Servo.h then analogWrite) reference arms successfully, and its
    arm beep sounds different from what this ESP32 firmware's ESC produces
    - narrowing the remaining gap down from "wrong timing" (already ruled
    out - esctest loopback confirmed <1us accuracy) to "wrong arm value".
    The ESP8266 reference deliberately arms at 900us, explicitly below its
    calibrated 1000us MIN, "to guarantee arming succeeds even if the ESP's
    pulse drifts slightly" (per its own comment). This firmware was arming
    at exactly ESC_SAFE_US=1000us - the same value BLHeliSuite calibrat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
    [ECU_TestV1_EGT_DRY_START_PATCH.ino]
2026-07-28 Add ECU Manual V1: minimal Serial-only, fully-manual firmware rewrite
    Fresh firmware keeping only the two read-only sensor subsystems from
    ECU_TestV1_EGT_DRY_START_PATCH - RPM measurement (interrupt + period/
    window, glitch filter, adaptive mask, rest-guard) and EGT (MAX31855) -
    and dropping every automatic actuator path: no auto-start state machine,
    no checklist interlock, no cooldown, no comm watchdog, no fuel
    closed-loop. Each output (starter/pump ESC, valve1/2, igniter) is now
    commanded directly over Serial and holds until changed; nothing turns an
    output on by itself.
    Carried over the hard-won ESC fixes: raw LEDC PWM (not ESP32Servo, which
    disturbs the RPM ISR), duty computed from the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
    [ECU_ManualV1.ino]
2026-07-29 Fix continuous telemetry update & Web Serial UI parsing in ECU_ManualV1 and index.html
    [ECU_ManualV1.ino]
2026-07-29 v2.4: Upgrade to CRC-8 checksum, add dual serial log for WEB_DATA, and add serial disconnect button
2026-07-30 Update ECU_ManualV1 to v3.9 with Microsecond Average RPM filter
2026-07-30 feat: implement adaptive PWM-to-RPM learning and robust signal noise classification in ESP32 firmware with web control tool
    [ECU_ManualV1.ino]
2026-07-30 feat: implement adaptive PWM-to-RPM learning and RPM noise classification for ECU firmware
    [ECU_ManualV1.ino]
2026-07-31 feat: implement adaptive PWM-to-RPM learning and RPM noise classification logic in firmware
    [ECU_ManualV1.ino]
2026-07-31 feat: implement adaptive PWM-to-RPM learning and robust signal monitoring in ECU firmware with companion web tool
2026-07-31 docs: add missing RC, GSU, and Button pins to README pinout
2026-07-31 feat: define missing hardware pins and implement heartbeat LED on IO2. Bump version to 4.4
    [ECU_ManualV1.ino]
2026-07-31 feat: implement emergency purge stop and 3s hold total shutdown logic for button and Web UI (v4.5)
2026-07-31 feat: implement adaptive PWM-to-RPM learning and RPM noise classification firmware with web interface support
    [ECU_ManualV1.ino]
2026-07-31 feat: initialize ECU firmware project with RPM sensing logic, adaptive PWM-to-RPM learning, and hardware documentation
2026-08-01 feat: implement adaptive PWM-to-RPM learning and S-curve ramp control for ECU firmware
2026-08-03 Remove esccal; debounce+clamp EGT overtemp to stop false emergency trips
    Two fixes on the main ECU_ManualV1 firmware:
    1. Remove the "esccal" throttle-range calibration command entirely (state
    vars, both command handlers, the loop auto-drop, and the help line). It
    is no longer used - the ESC is calibrated externally by feeding the
    pulse directly - and it was broken anyway: it set startUs/pumpUs to MAX
    without updating the ramp targets, so updateRamps() snapped them back to
    ~1000us on the same loop iteration, so the MAX endpoint was never held.
    2. Harden the projected-EGT overtemp protection (PEGT 3s > 740C) against
    thermocouple/MAX31855 glitches. A single bad sample can pr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
    [ECU_ManualV1.ino]
2026-08-03 docs: update project README and add documentation to the current project directory
2026-08-03 feat: add Web Serial dashboard for real-time ECU monitoring and control and create initial Arduino firmware structure
2026-08-19 feat: upgrade system to v7.8 and integrate Web Serial Flasher
    - Bumped project version to 7.8 in documentation.
    - Integrated `esptool-js` into the Web Dashboard for browser-based firmware flashing.
    - Updated firmware with safety limit configurations and OTA update libraries.
    - Standardized version bumping policy in development guidelines.
    [Bendix Sleeve.stl, Brushed motor mount.stl, Brushless motor mount.stl]
2026-08-19 feat: upgrade firmware to v7.9 and optimize deployment
    - Increase otaUrl buffer size
    - Move EGT code block
    - Update README versioning
    - Fix GitHub Actions workflow deployment logic
    [ECU_ManualV1.ino]
2026-08-19 auto: bump version & compile ESP32 firmware.bin
2026-08-22 new trợ lý
2026-08-22 Bây giờ khi xảy ra CẢNH BÁO QUÁ NHIỆT (ERR:E02), nếu hệ thống phát hiện thanh trượt mô-tơ đề (Starter) của bạn đang tắt (<= 1000µs), nó sẽ: Tự động cắt ngay Bơm nhiên liệu về 1000µs. Tự động đẩy mô-t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
2026-08-23 add new with log
    [ECU000.CSV, ECU001.CSV, ECU002.CSV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]
2026-08-24 add new
    [Bendix Sleeve.stl, Bendix Sleeve_10.4mm_NoSpring_Reinforced.stl, Bendix Sleeve_10mm_NoSpring_Reinforced.stl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]
